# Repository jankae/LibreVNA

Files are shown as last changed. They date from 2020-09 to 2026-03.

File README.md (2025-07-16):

# LibreVNA

  

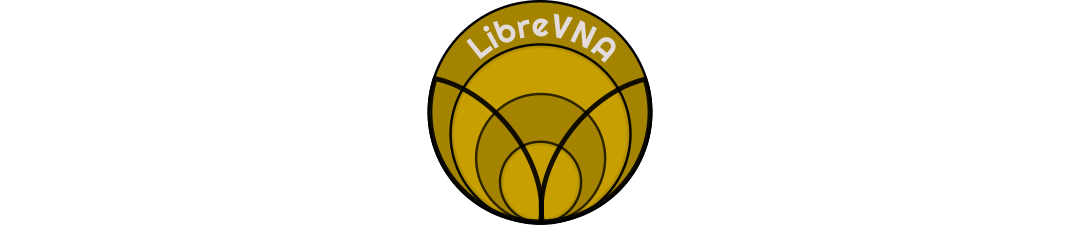
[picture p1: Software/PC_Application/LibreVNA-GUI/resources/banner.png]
LibreVNA


**100kHz to 6GHz VNA**

This is the improved version of my [first attempt](https://www.github.com/jankae/VNA) at a VNA.

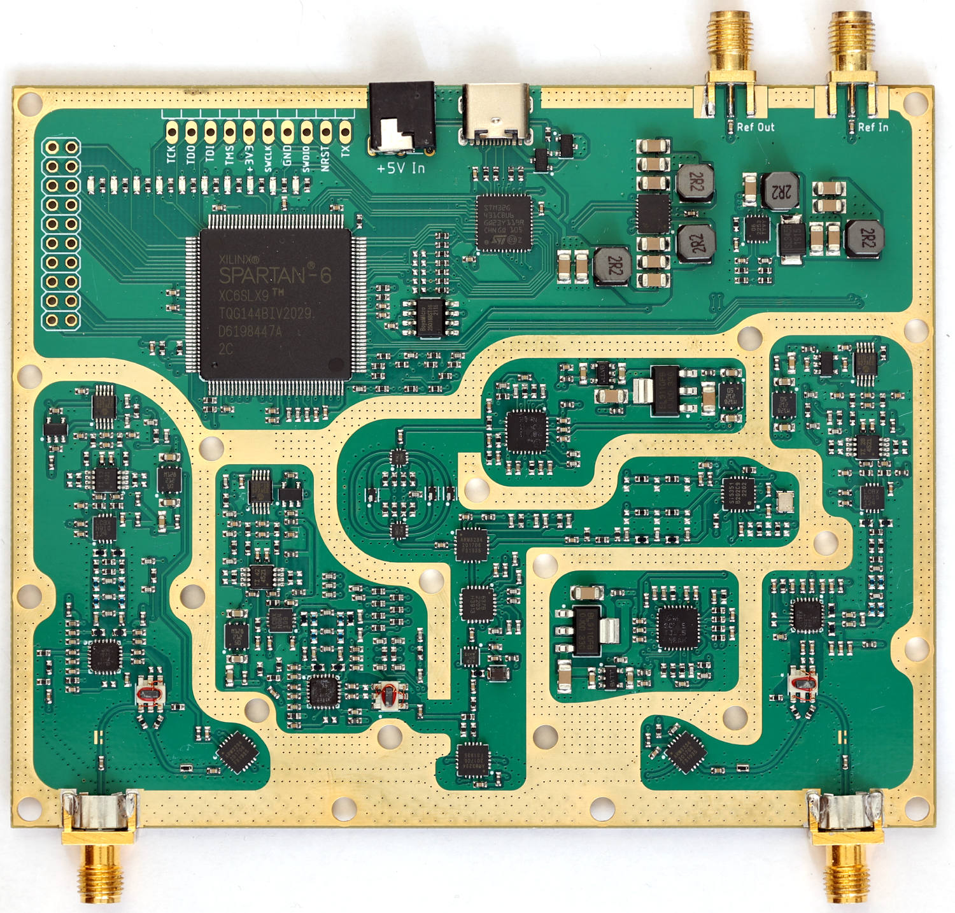
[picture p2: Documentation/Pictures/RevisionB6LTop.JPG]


## GUI Installation

### Windows
* Download the latest [Release](https://github.com/jankae/LibreVNA/releases) and unpack the zip file
* Start the included LibreVNA-GUI.exe
* No installation or driver is required, simply move the extracted folder somewhere convenient

### Ubuntu
* Download the latest [Release](https://github.com/jankae/LibreVNA/releases) and unpack the zip file
* Install the required libraries:
```console
sudo apt install qt6-base-dev libqt6svg6
```
* Install the udev rule (otherwise you don't have the permissions to access the USB device):
```console
wget https://raw.githubusercontent.com/jankae/LibreVNA/master/Software/PC_Application/51-vna.rules
sudo cp 51-vna.rules /etc/udev/rules.d
```
* Either reboot or reload the udev rules manually:
```console
sudo udevadm control --reload-rules
sudo udevadm trigger
```
* You can now start GUI:
```console
cd $UNPACKED_ZIP_FOLDER$
./LibreVNA-GUI
```

### MacOS
* Download the latest [Release](https://github.com/jankae/LibreVNA/releases)
  * If you are using MacOS 14+ use the release with `latest` in the name.
  * If you are using MacOS >13.7 use the release with  `13.7` in the name.
* Unpack the zip file and move LibreVNA-GUI.app to your `/Applications` folder.
* Start LibreVNA-GUI.app and add a security exception to allow the Mac to run the app with an "untrusted" signing key.
* Launch app again.

## Quick Start
* You can find released versions of the GUI application and the device firmware [here](https://github.com/jankae/LibreVNA/releases).
* If you would like to try out the newest features, the compiled versions of each commit can be found [here](https://github.com/jankae/LibreVNA/actions) (but keep in mind that some features might be unstable or incomplete). If you are having trouble downloading them, please refer to this [guide](Documentation/DeveloperInfo/DownloadActionBuilds.md).
* An (incomplete) [user manual](Documentation/UserManual/manual.pdf) is also available.
* If you would like to control the LibreVNA with a script, see the [SCPI Programming Guide](Documentation/UserManual/ProgrammingGuide.pdf).

Please also take a look at the [FAQ](Documentation/FAQ.md).

If you notice bugs or have ideas for improvements, please create an issue for that.

For general questions or discussions, the [LibreVNA group](https://groups.io/g/LibreVNA-support/) is probably the best place.

### Preliminary specifications
Some [specifications](Documentation/UserManual/specsheet.pdf) are available but this project is still under development and the specifications might change.

There are also some initial [example measurements](Documentation/Measurements/Measurements.md).

## How does it work?
The PCB is really only the RF frontend with some processing power. Everything else is handled in the PC application once the data is transferred via USB. You can try out the application without the PCB (obviously no measurements are possible, but you can import provided example measurements and get an idea about what it can and can't do).
### RF path:


* The main clock source is an Si5351C, providing all the required clocks for the different blocks. It also serves as the stimulus source for frequencies below 25MHz. Its own reference clock is either a 26MHz crystal or an external 10MHz signal.
* The stimulus source for frequencies above 25MHz is a MAX2871. Its output signal is slightly filtered to reduce the amount of harmonics.
* The stimulus signal power can be adjusted between approximately -42 and -10dbm with a digital attenuator (RFSA3714).
* After the amplifier(TRF37A73) the signal is split and the weaker part of it fed into the reference receiver.
* The stronger part of the signal can be routed to either port. In each signal path, two RF switches are used in series to achieve higher isolation between the ports.
* Instead of directional couplers, resistive return-loss-bridges are used (easier to implement for wide bandwidth).
* Both ports have completely separated receive paths. This increases BOM cost but allows measuring two parameters at once (S11 and S21 or S22 and S12). It also avoids potential isolation issues that could arise if the receive paths would merge into a single mixer/ADC.
* Each receiver consists of two down-convert mixers. The 1.IF sits at 60MHz, the 2.IF 250kHz.
* The ADCs are sampling the final IF with 16bit@800kHz.

### Digital section:


* The central element is the Spartan6 FPGA. It handles all communication with the RF blocks and samples the ADCs. This allows for nearly instant switching of the measurement frequency, only limited by the settling time of the PLLs.
* The microcontroller handles the setup of the sweep in the FPGA, extracts and preprocesses the measurements and passes them on through USB.
* The flash contains the FPGA bitstream. Because the microcontroller has access to the flash, no FPGA-related hardware tools (such as JTAG programmers) are needed, everything can be updated via USB.

### Power supply:


* Everything is powered from USB (or optionally by external 5V DC)
* Almost every RF block has its own local regulater, preventing noise and signals coupling into the supply lines from propagating across the whole PCB

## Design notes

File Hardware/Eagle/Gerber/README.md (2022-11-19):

### Stackup
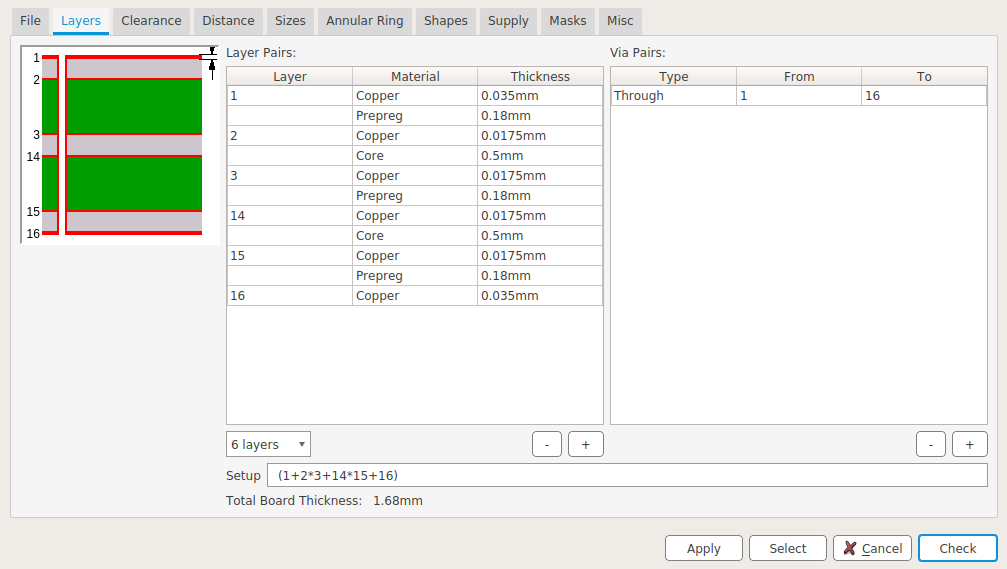
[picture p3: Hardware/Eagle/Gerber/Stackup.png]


* Exact thickness of the cores is not important, as long as they are significantly thicker than the prepregs
* Recommended Prepreg: 7628
* Example stackup from manufacturer: [JLC06161H-7628 Stackup](https://jlcpcb.com/impedance)

### PCB size

122mm * 98mm

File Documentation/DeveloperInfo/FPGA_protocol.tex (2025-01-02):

\documentclass{article}
\usepackage
[
        a4paper,% other options: a3paper, a5paper, etc
        left=2cm,
        right=2cm,
        top=2cm,
        bottom=2cm,
        % use vmargin=2cm to make vertical margins equal to 2cm.
        % us  hmargin=3cm to make horizontal margins equal to 3cm.
        % use margin=3cm to make all margins  equal to 3cm.
]
{geometry}
\usepackage{tikz}
\usepackage{siunitx} 
\usepackage{minibox}
\DeclareSIUnit{\belmilliwatt}{Bm}
\DeclareSIUnit{\dBm}{\deci\belmilliwatt}

\pgfdeclarelayer{background}
\pgfdeclarelayer{foreground}
\pgfsetlayers{background,main,foreground}

\newcommand{\bitrect}[2]{
  \begin{pgfonlayer}{foreground}
    \draw [thick] (0,0) rectangle (#1,1);
    \pgfmathsetmacro\result{#1-1}
    \foreach \x in {1,...,\result}
      \draw [thick] (\x,1) -- (\x, 0.8);
  \end{pgfonlayer}
%  \node [below left, align=right] at (0,0) {Type \\ Reset};
  \bitlabels{#1}{#2}
}
\newcommand{\rwbits}[3]{
  \draw [thick] (#1,0) rectangle ++(#2,1) node[pos=0.5]{#3};
  \pgfmathsetmacro\start{#1+0.5}
  \pgfmathsetmacro\finish{#1+#2-0.5}
%  \foreach \x in {\start,...,\finish}
%    \node [below, align=center] at (\x, 0) {R/W \\ 0};
}
\newcommand{\robits}[3]{
  \begin{pgfonlayer}{background}
    \draw [thick, fill=lightgray] (#1,0) rectangle ++(#2,1) node[pos=0.5]{#3};
  \end{pgfonlayer}
  \pgfmathsetmacro\start{#1+0.5}
  \pgfmathsetmacro\finish{#1+#2-0.5}
%  \foreach \x in {\start,...,\finish}
%    \node [below, align=center] at (\x, 0) {RO \\ 0};
}
\newcommand{\bitlabels}[2]{
  \foreach \bit in {1,...,#1}{
     \pgfmathsetmacro\result{#2}
     \node [above] at (\bit-0.5, 1) {\pgfmathprintnumber{\result}};
   }
}

\begin{document}

\section{Digital Interface}
\begin{center}
\begin{tabular}{ c|c|c }
Pin & Direction & Function\\
 \hline
SCK & in & SCK for SPI communication/SCK for PLL communication\\
MOSI & in & MOSI for SPI communication/MOSI for PLL communication\\
MISO & out & MISO for SPI communication/MUX for PLL communication\\
NSS & in & Chip Select for SPI communication/LE for PLL communication\\
INTR & out & Active high interrupt indicator\\
RESET\footnotemark & in & FPGA reset\\
AUX1 & in & Selector for direct communication with Source PLL\\
AUX2 & in & Selector for direct communication with LO PLL\\
AUX3 & in & Active low sweep enable. Has to be high when changing settings\\
Trigger In\footnotemark & in & Trigger input for synchronization across devices\\
Trigger Out\footnotemark & Out & Trigger output for synchronization across devices\\
\end{tabular}
\end{center}
\footnotetext[1]{Reset is named "MCU\_FPGA\_UNUSED1" in the schematic as this is a later software addition}
\footnotetext[2]{Trigger In is named "MCU\_FPGA\_UNUSED2" in the schematic as this is a later software addition}
\footnotetext[3]{Trigger Out is named "MCU\_FPGA\_UNUSED3" in the schematic as this is a later software addition}
Depending on the voltage on AUX1/AUX2 the SPI port controls either the FPGA or one of the MAX2871 PLLs:
\begin{center}
\begin{tabular}{ c|c|c }
AUX1 & AUX2 & Function\\
 \hline
low & low & SPI communication with FPGA\\
high & low & Direct feedthrough of SCK, MOSI, MISO and NSS to Source PLL\\
low & high & Direct feedthrough of SCK, MOSI, MISO and NSS to LO PLL\\
high & high & Invalid\\
\end{tabular}
\end{center}
When communicating with a PLL, the MUX output of the MAX2871 is forwarded to MISO and the NSS signal is forwarded to the LE pin. As the LE pin should stay low until after a valid register has been shifted in (see MAX2871 datasheet), set NSS low before switching to PLL communication mode.

\section{SPI Protocol}
Each SPI transfer starts with pulling NSS low and ends with NSS returning to high level. SPI communication is done in words of 16\,bits. The first word after NSS is pulled low is the command word and determines the amount and meaning of the following words.
The word received while transmitting the command word is the interrupt status register:
\begin{center}
\begin{tikzpicture}
\bitrect{16}{16-\bit}
\robits{0}{10}{reserved}
\rwbits{10}{1}{DFT}
\rwbits{11}{1}{SH}
\rwbits{12}{1}{OR}
\rwbits{13}{1}{ND}
\rwbits{14}{1}{SU}
\rwbits{15}{1}{LU}
\end{tikzpicture}
\end{center}
\begin{itemize}
\item \textbf{DFT:} New DFT result available (see section~\ref{dft}).
\item \textbf{SH:} Sweep halted due to halt bit set. Sweep will be resumed once the resume command is issued.
\item \textbf{OR:} Data overrun occured (only cleared by resetting the FPGA)
\item \textbf{ND:} New data available
\item \textbf{SU:} Source unlocked
\item \textbf{LU:} LO unlocked
\end{itemize}
\subsection{Writing a register}
Writing a register requires the transfer of two words: First the control word selecting the destination address and a second word containing the new register value:
\begin{center}
\begin{tikzpicture}
\bitrect{16}{16-\bit}
\rwbits{0}{1}{1}
\rwbits{1}{1}{0}
\rwbits{2}{1}{0}
\robits{3}{8}{reserved}
\rwbits{11}{5}{Register Address}
\end{tikzpicture}
\begin{tikzpicture}
\bitrect{16}{16-\bit}
\rwbits{0}{16}{Register Value}
\end{tikzpicture}
\end{center}
\subsection{Writing SweepConfig}
Initiate the sweep config transfer by sending the command word:
\begin{center}
\begin{tikzpicture}
\bitrect{16}{16-\bit}
\rwbits{0}{1}{0}
\rwbits{1}{1}{0}
\rwbits{2}{1}{0}
\rwbits{3}{13}{Sweep point}
\end{tikzpicture}
\end{center}
The maximum number of points per sweep is 4501, thus the highest valid value for "Sweep point" is 4500. After the control word, send the six words of the sweep config (see section~\ref{sweepconfig}) while keeping NSS low. The sweep config is transmitted MSB first.

\subsection{Reading a sampling result}
Whenever the ND bit in the interrupt status register is set, new sampling data is available and can be read via SPI. It has to be read before the next sampling data arrives otherwise the old data will be overwritten.

Initiate the reading of sampling data by sending the command word:
\begin{center}
\begin{tikzpicture}
\bitrect{16}{16-\bit}
\rwbits{0}{1}{1}
\rwbits{1}{1}{1}
\rwbits{2}{1}{0}
\robits{3}{13}{reserved}
\end{tikzpicture}
\end{center}
Afterwards, read up to 19 words before setting NSS high. These 19 words will contain the sampling result (see section~\ref{result}), transmitted with the least significant word first.

\subsection{Resuming a halted sweep}
When the halt bit is set in the SweepConfig, the FPGA will configure the Source and LO as requested but will not start the settling timer (and subsequently the sampling process) until this resume command is issued. The halted sweep is indicated by the sweep halted bit in the status register.
\begin{center}
\begin{tikzpicture}
\bitrect{16}{16-\bit}
\rwbits{0}{1}{0}
\rwbits{1}{1}{0}
\rwbits{2}{1}{1}
\robits{3}{13}{reserved}
\end{tikzpicture}
\end{center}

\subsection{Reading ADC limits}
The FPGA keeps track of the highest and lowest sample of each ADC to detect saturation and verify signal levels.

Initiate the reading of ADC limit data by sending the command word:
\begin{center}
\begin{tikzpicture}
\bitrect{16}{16-\bit}
\rwbits{0}{1}{1}
\rwbits{1}{1}{1}
\rwbits{2}{1}{1}
\robits{3}{13}{reserved}
\end{tikzpicture}
\end{center}
Afterwards, read 6 words before setting NSS high. These 6 words will contain the sampling result:

\begin{center}
\begin{tikzpicture}
\bitrect{16}{96-\bit}
\rwbits{0}{16}{Port 1 minimum}
\end{tikzpicture}
\begin{tikzpicture}
\bitrect{16}{80-\bit}
\rwbits{0}{16}{Port 1 maximum}
\end{tikzpicture}
\begin{tikzpicture}
\bitrect{16}{64-\bit}
\rwbits{0}{16}{Port 2 minimum}
\end{tikzpicture}
\begin{tikzpicture}
\bitrect{16}{48-\bit}
\rwbits{0}{16}{Port 2 maximum}
\end{tikzpicture}
\begin{tikzpicture}
\bitrect{16}{32-\bit}
\rwbits{0}{16}{Reference minimum}
\end{tikzpicture}
\begin{tikzpicture}
\bitrect{16}{16-\bit}
\rwbits{0}{16}{Reference maximum}
\end{tikzpicture}
\end{center}

\subsection{Resetting the ADC limit}
Issuing this command result in all minimum values set to 32767 and all maximum values set to -32768.
\begin{center}
\begin{tikzpicture}
\bitrect{16}{16-\bit}
\rwbits{0}{1}{0}
\rwbits{1}{1}{1}
\rwbits{2}{1}{1}
\robits{3}{13}{reserved}
\end{tikzpicture}
\end{center}

\subsection{Reading the DFT result}
Initiate the reading of the DFT result (see section~\ref{dft}) by sending the command word:
\begin{center}
\begin{tikzpicture}
\bitrect{16}{16-\bit}
\rwbits{0}{1}{1}
\rwbits{1}{1}{0}
\rwbits{2}{1}{1}
\robits{3}{13}{reserved}
\end{tikzpicture}
\end{center}
Afterwards, read 12 words before setting NSS high. These 12 words will contain the first bin of the DFT, the least significant word is transmitted first:
\begin{center}
\begin{tikzpicture}
\bitrect{16}{192-\bit}
\rwbits{0}{16}{Port 1 I[47:32]}
\end{tikzpicture}
\begin{tikzpicture}
\bitrect{16}{176-\bit}
\rwbits{0}{16}{Port 1 I[31:16]}
\end{tikzpicture}
\begin{tikzpicture}
\bitrect{16}{168-\bit}
\rwbits{0}{16}{Port 1 I[15:0]}
\end{tikzpicture}
\begin{tikzpicture}
\bitrect{16}{144-\bit}
\rwbits{0}{16}{Port 1 Q[47:32]}
\end{tikzpicture}
\begin{tikzpicture}
\bitrect{16}{128-\bit}
\rwbits{0}{16}{Port 1 Q[31:16]}
\end{tikzpicture}
\begin{tikzpicture}
\bitrect{16}{112-\bit}
\rwbits{0}{16}{Port 1 Q[15:0]}
\end{tikzpicture}
\begin{tikzpicture}
\bitrect{16}{96-\bit}
\rwbits{0}{16}{Port 2 I[47:32]}
\end{tikzpicture}
\begin{tikzpicture}
\bitrect{16}{80-\bit}
\rwbits{0}{16}{Port 2 I[31:16]}
\end{tikzpicture}
\begin{tikzpicture}
\bitrect{16}{64-\bit}
\rwbits{0}{16}{Port 2 I[15:0]}
\end{tikzpicture}
\begin{tikzpicture}
\bitrect{16}{48-\bit}
\rwbits{0}{16}{Port 2 Q[47:32]}
\end{tikzpicture}
\begin{tikzpicture}
\bitrect{16}{32-\bit}
\rwbits{0}{16}{Port 2 Q[31:16]}
\end{tikzpicture}
\begin{tikzpicture}
\bitrect{16}{16-\bit}
\rwbits{0}{16}{Port 2 Q[15:0]}
\end{tikzpicture}
\end{center}
Repeating this procedure will return the next DFT bin. For each bin, the CS pin has to be toggled and the command word needs to be sent again (each DFT bin requires a new SPI transaction). The DFT interrupt is reset once all bins have been read. Alternatively, toggling the DFT off and on (by disabling and enabling its interrupt) will also reset the interrupt flag.

\section{Registers}
\subsection{Interrupt Mask Register: 0x00}
\begin{center}
\begin{tikzpicture}
\bitrect{16}{16-\bit}
\robits{0}{10}{reserved}
\rwbits{10}{1}{DFTIE}
\rwbits{11}{1}{SHIE}
\rwbits{12}{1}{ORIE}
\rwbits{13}{1}{NDIE}
\rwbits{14}{1}{SUIE}
\rwbits{15}{1}{LUIE}
\end{tikzpicture}
\end{center}
\begin{itemize}
\item \textbf{DFTIE:} DFT interrupt enable. This bit also enables the DFT (see section~\ref{dft}).
\item \textbf{SHIE:} Sweep halted interrupt enable
\item \textbf{ORIE:} Data overrun interrupt enable 
\item \textbf{NDIE:} New data interrupt enable
\item \textbf{SUIE:} Source unlocked interrupt enable
\item \textbf{LUIE:} LO unlocked interrupt enable 
\end{itemize}

\subsection{Sweep Points Register: 0x01}
\begin{center}
\begin{tikzpicture}
\bitrect{16}{16-\bit}
\rwbits{0}{16}{Number of points per sweep - 1}
\end{tikzpicture}
\end{center}
The register contains the number of points per sweep negative one, e.g. set to 11b if the sweep contains four points.

\subsection{Samples Per Point Register: 0x02}
\label{reg:spp}
\begin{center}
\begin{tikzpicture}
\bitrect{16}{16-\bit}
\robits{0}{3}{reserved}
\rwbits{3}{13}{SPP[12:0]}
\end{tikzpicture}
\end{center}
\begin{itemize}
\item \textbf{SPP[12:0]:} The register contains the number of samples per point in increments of 16 samples (e.g. SPP=0b0000001000=0x08 uses 128 samples per point). The value of this register is only used if SweepConfig[92:90] is set to 000. Otherwise it is overwritten for the sweep point with one of seven preselected values.
\end{itemize}

\subsection{System Control Register: 0x03}
\begin{center}
\begin{tikzpicture}
\footnotesize
\bitrect{16}{16-\bit}
\rwbits{0}{1}{P1EN}
\rwbits{1}{1}{P2EN}
\rwbits{2}{1}{REN}
\rwbits{3}{1}{AMEN}
\rwbits{4}{1}{SOEN}
\rwbits{5}{1}{LOEN}
\rwbits{6}{1}{RLED}
\rwbits{7}{1}{LED6}
\rwbits{8}{1}{LED7}
\rwbits{9}{2}{Window[1:0]}
\rwbits{11}{1}{SCEN}
\rwbits{12}{1}{LCEN}
\robits{13}{1}{reserved}
%\rwbits{13}{1}{EXP2}
\rwbits{14}{1}{SYM}
\rwbits{15}{1}{PSEN}
\end{tikzpicture}
\end{center}
\begin{itemize}
\item \textbf{P1EN:} Port 1 Mixers/Amplifier enable
\item \textbf{P2EN:} Port 2 Mixers/Amplifier enable
\item \textbf{REN:} Reference Mixers/Amplifier enable
\item \textbf{AMEN:} Source amplifier enable
\item \textbf{SOEN:} Source enable
\item \textbf{LOEN:} LO enable
\item \textbf{RLED:} External frequency LED control
\item \textbf{LED6:}{User LED 6 control}
\item \textbf{LED7:}{User LED 7 control}
\item \textbf{Window[1:0]:}{Type of window to be used in calculation of real/imag of the sampling result}
\begin{center}
\begin{tabular}{ c|c }
Setting & Window type\\
 \hline
00 & Rectangular (no window)\\
01 & Kaiser\\
10 & Hann\\
11 & Flat Top\\
\end{tabular}
\end{center}
\item \textbf{SCEN:}{Source chip enable}
\item \textbf{LCEN:}{LO chip enable}
%\item \textbf{EXP1:}{Excite Port1 during sweep}
\item \textbf{SYM:}{Sync master, see also section~\ref{synchronization}. If multiple devices are combined, exactly one must have this bit set.}
\item \textbf{PSEN:}{Port switch enable}
\end{itemize}

\subsection{ADC Prescaler register: 0x04}
\label{reg:ADC}
\begin{center}
\begin{tikzpicture}
\bitrect{16}{16-\bit}
\robits{0}{8}{reserved}
\rwbits{8}{8}{Presc[7:0]}
\end{tikzpicture}
\end{center}
\begin{itemize}
\item \textbf{Presc[7:0]:} Amount of FPGA clock cycles between ADC samples.
$$ SR_{ADC} = \frac{\SI{102.4}{\mega\hertz}}{Presc} $$
The minimum value for this register is 112, which results in a samplerate of roughly \SI{914.3}{\kilo\hertz}. If Presc is set to a lower value, the data acquisition from the ADC is not done when the next sample starts and samples will be skipped.
\end{itemize}

\subsection{Phase Increment: 0x05}
\label{reg:phaseinc}
\begin{center}
\begin{tikzpicture}
\bitrect{16}{16-\bit}
\robits{0}{4}{reserved}
\rwbits{4}{12}{Phase Increment[11:0]}
\end{tikzpicture}
\end{center}
\begin{itemize}
\item \textbf{Phase Increment[7:0]:} Phase angle between ADC samples for DFT bin calculation in $\frac{2\pi}{4096}$rad.
For a given ADC samplerate $SR_{ADC}$ and final IF frequency $f_{IF2}$ set this value to
$$ PhaseInc = \frac{4096 * f_{IF2}}{SR_{ADC}} $$
For the the default IF frequency of $f_{IF2} = \SI{250}{\kilo\hertz}$ this evaluates to 10*Presc (see ADC prescaler register).
\end{itemize}

\subsection{Sweep setup: 0x06}
Each point in the sweep is done in stages. Each stage consists of (optionally) routing the source signal to one of the ports and sampling of all ADCs. A "new data" interrupt is triggered after each stage.
\label{reg:sweepsetup}
\begin{center}
\begin{tikzpicture}
\bitrect{16}{16-\bit}
\rwbits{0}{3}{Stages}
\rwbits{3}{1}{SYNC}
\robits{4}{6}{reserved}
\rwbits{10}{3}{Port 1 stage}
\rwbits{13}{3}{Port 2 stage}
\end{tikzpicture}
\end{center}
\begin{itemize}
\item \textbf{Stages} Number of stages per point - 1. Normally the number of stages is equal to the number of ports but it can also be less (e.g. if only S11 is measured).
\item \textbf{SYNC:} Enables synchronization mode (see section~\ref{synchronization}).
\item \textbf{Port 1 stage} Number of stage during which the source signal is routed to port 1. Must not have the same value as Port 2 stage.
\item \textbf{Port 2 stage} Number of stage during which the source signal is routed to port 2. Must not have the same value as Port 1 stage.
\end{itemize}

\subsection{Hardware override register: 0x07}
Allows overwriting hardware settings, regardless of whether a sweep is active or not.
\label{reg:hw_override}
\begin{center}
\begin{tikzpicture}
\bitrect{16}{16-\bit}
\rwbits{0}{1}{OWE}
\rwbits{1}{7}{Attenuator[6:0]}
\rwbits{8}{2}{SourceFilter}
\rwbits{10}{1}{BS}
\rwbits{11}{1}{P1EN}
\rwbits{12}{1}{P2EN}
\robits{13}{3}{reserved}
\end{tikzpicture}
\end{center}
\begin{itemize}
\item \textbf{OWE:} Overwrite enable. If 1, this register is used to configure the hardware. If 0, all other bits in the register are ignored. Must be set to 0 for valid sweep operation.
\item \textbf{Attenuator[6:0]:} Attenuator setting
\item \textbf{SourceFilter:} Low pass filter selection for source signal
\begin{center}
\begin{tabular}{ c|c }
Setting & Selected Band\\
 \hline
00 & \SIrange{0}{900}{\mega\hertz}\\
01 & \SIrange{900}{1800}{\mega\hertz}\\
10 & \SIrange{1800}{3500}{\mega\hertz}\\
11 & \SIrange{3500}{6000}{\mega\hertz}\\
\end{tabular}
\end{center}
\item \textbf{BS: Band select.} Set to 0 for highband, set to 1 for lowband.
\item \textbf{P1EN:} Route signal to port 1. Must not be enabled at the same time as P2EN.
\item \textbf{P2EN:} Route signal to port 2. Must not be enabled at the same time as P1EN.
\end{itemize}

\subsection{MAX2871 Default Values Registers: 0x08-0x0F}
See datasheet of MAX2871 for bit descriptions. Bits for the fields N, FRAC, M, VCO and DIV\_A are "don't care" as they will be overwritten by the SweepConfig setting.
\begin{center}
\begin{tikzpicture}
\bitrect{16}{16-\bit}
\rwbits{0}{16}{MAX2871 Register 0[15:0]}
\end{tikzpicture}
\begin{tikzpicture}
\bitrect{16}{16-\bit}
\rwbits{0}{16}{MAX2871 Register 0[31:16]}
\end{tikzpicture}
\begin{tikzpicture}
\bitrect{16}{16-\bit}
\rwbits{0}{16}{MAX2871 Register 1[15:0]}
\end{tikzpicture}
\begin{tikzpicture}
\bitrect{16}{16-\bit}
\rwbits{0}{16}{MAX2871 Register 1[31:16]}
\end{tikzpicture}
\begin{tikzpicture}
\bitrect{16}{16-\bit}
\rwbits{0}{16}{MAX2871 Register 3[15:0]}
\end{tikzpicture}
\begin{tikzpicture}
\bitrect{16}{16-\bit}
\rwbits{0}{16}{MAX2871 Register 3[31:16]}
\end{tikzpicture}
\begin{tikzpicture}
\bitrect{16}{16-\bit}
\rwbits{0}{16}{MAX2871 Register 4[15:0]}
\end{tikzpicture}
\begin{tikzpicture}
\bitrect{16}{16-\bit}
\rwbits{0}{16}{MAX2871 Register 4[31:16]}
\end{tikzpicture}
\end{center}

\subsection{DFT registers}
\label{dft}
In addition to the single bin DFT configured through the ADC prescaler and phase increment registers (see \ref{reg:ADC} and \ref{reg:phaseinc}), the FPGA also includes a multiple point DFT. This DFT only operates on the port 1 and port 2 receivers and is intended to speed up spectrum analyzer measurements. If enabled, the DFT runs in parallel to all other calculations.

The DFT has a fixed number of bins (96), but the frequencies these bins correspond to can be changed.

\subsubsection{DFT\_FIRST\_BIN: 0x12}
\begin{center}
\begin{tikzpicture}
\bitrect{16}{16-\bit}
\rwbits{0}{16}{DFT\_FIRST\_BIN[15:0]}
\end{tikzpicture}
\end{center}
\begin{itemize}
\item \textbf{DFT\_FIRST\_BIN[15:0]:} This value determines the frequency corresponding to the first DFT bin.
$$ f_{firstBin} =  \frac{SR_{ADC} * DFT\_FIRST\_BIN}{2^{16}}$$
\end{itemize}

\subsubsection{DFT\_FREQ\_SPACING: 0x13}
\begin{center}
\begin{tikzpicture}
\bitrect{16}{16-\bit}
\rwbits{0}{16}{DFT\_FREQ\_SPACING[15:0]}
\end{tikzpicture}
\end{center}
\begin{itemize}
\item \textbf{DFT\_FREQ\_SPACING[15:0]:} This value determines the frequency difference between bins.
$$ \Delta f =  \frac{SR_{ADC} * DFT\_FREQ\_SPACING}{2^{24}}$$
\end{itemize}

\subsection{SETTLING\_TIME: 0x14}
\begin{center}
\begin{tikzpicture}
\bitrect{16}{16-\bit}
\rwbits{0}{16}{SETTLING\_TIME[15:0]}
\end{tikzpicture}
\end{center}
\begin{itemize}
\item \textbf{SETTLING\_TIME[19:0]:} This value determines the time delay between applying the stimulus signal and the beginning of the ADC sampling.
$$ t_{delay} =  \frac{1}{\SI{102.4}{\mega\hertz}} SETTLING\_TIME $$
\end{itemize}
\subsection{SETTLING\_TIME: 0x15}
\begin{center}
\begin{tikzpicture}
\bitrect{16}{16-\bit}
\robits{0}{12}{reserved}
\rwbits{12}{4}{SETTLING\_TIME[19:16]}
\end{tikzpicture}
\end{center}

\section{SweepConfig}
\label{sweepconfig}
The SweepConfig contains data for the source and LO1 PLL as well as the attenuator and source filter. Each point in the sweep, needs a valid SweepConfig before the sweep is started.

\begin{center}
\begin{tikzpicture}
\bitrect{16}{96-\bit}
\rwbits{0}{1}{HS}
%\rwbits{1}{2}{SettlingTime}
\rwbits{1}{1}{\tiny LO N[6]}
\rwbits{2}{1}{\minibox{\tiny Source\\N[6]}}
\rwbits{3}{3}{Samples}
\rwbits{6}{2}{SourceFilter}
\rwbits{8}{8}{LO M[11:4]}
\end{tikzpicture}
\begin{tikzpicture}
\bitrect{16}{80-\bit}
\rwbits{0}{4}{LO M[3:0]}
\rwbits{4}{12}{LO FRAC[11:0]}
\end{tikzpicture}
\begin{tikzpicture}
\bitrect{16}{64-\bit}
\rwbits{0}{3}{LO DIV\_A[2:0]}
\rwbits{3}{6}{LO VCO[5:0]}
\rwbits{9}{6}{LO N[5:0]}
\rwbits{15}{1}{BS}
\end{tikzpicture}
\begin{tikzpicture}
\bitrect{16}{48-\bit}
\rwbits{0}{2}{PWR[1:0]}
\rwbits{2}{7}{Attenuator[6:0]}
\rwbits{9}{7}{Source M[11:5]}
\end{tikzpicture}
\begin{tikzpicture}
\bitrect{16}{32-\bit}
\rwbits{0}{5}{Source M[4:0]}
\rwbits{5}{11}{Source FRAC[11:1]}
\end{tikzpicture}
\begin{tikzpicture}
\bitrect{16}{16-\bit}
\rwbits{0}{1}{F[0]}
\rwbits{1}{3}{Source DIV\_A[2:0]}
\rwbits{4}{6}{Source VCO[5:0]}
\rwbits{10}{6}{Source N[5:0]}
\end{tikzpicture}
\end{center}
\begin{itemize}
\item \textbf{HS: Halt sweep.} If set, settling and sampling of this sweep point will be postponed until the sweep resume command is issued.
%\item \textbf{SettlingTime:} Amount of time between locking of PLLs and beginning of ADC sampling
%\begin{center}
%\begin{tabular}{ c|c }
%Setting & Time\\
 %\hline
%00 & \SI{20}{\micro\second}\\
%01 & \SI{60}{\micro\second}\\
%10 & \SI{180}{\micro\second}\\
%11 & \SI{540}{\micro\second}\\
%\end{tabular}
%\end{center}
\item \textbf{Samples:} Number of ADC samples to take
\begin{center}
\begin{tabular}{ c|c|c }
Setting & Samples & Equivalent IF bandwidth\\
 \hline
000 & Defined by SPP register & \SI{914}{\kilo\hertz}/SPP\\
001 & 96 & \SI{10}{\kilo\hertz}\\
010 & 304 & \SI{3}{\kilo\hertz}\\
011 & 912 & \SI{1}{\kilo\hertz}\\
100 & 3040 & \SI{300}{\hertz}\\
101 & 9136 & \SI{100}{\hertz}\\
110 & 30464 & \SI{30}{\hertz}\\
111 & 91392 & \SI{10}{\hertz}\\
\end{tabular}
\end{center}
\item \textbf{SourceFilter:} Low pass filter selection for source signal
\begin{center}
\begin{tabular}{ c|c }
Setting & Selected Band\\
 \hline
00 & \SIrange{0}{900}{\mega\hertz}\\
01 & \SIrange{900}{1800}{\mega\hertz}\\
10 & \SIrange{1800}{3500}{\mega\hertz}\\
11 & \SIrange{3500}{6000}{\mega\hertz}\\
\end{tabular}
\end{center}
\item \textbf{BS: Band select.} Set to 0 for highband, set to 1 for lowband.
\item \textbf{PWR:} Power setting of source PLL. Will be written to register 4, bits [4:3] of the source PLL, controlling the output power of output A.
\begin{center}
\begin{tabular}{ c|c }
Setting & Selected Power\\
 \hline
00 & \SI{-4}{\dBm}\\
01 & \SI{-1}{\dBm}\\
10 & \SI{2}{\dBm}\\
11 & \SI{5}{\dBm}\\
\end{tabular}
\end{center}
\item \textbf{Attenuator:} Attenuation of source signal in \SI{0.25}{\decibel}.
\end{itemize}

\section{Sampling Result}
\label{result}
Each point in the sweep generates a sampling results for each stage (see section~\ref{reg:sweepsetup}).
\begin{center}
\begin{tikzpicture}
\bitrect{16}{304-\bit}
\rwbits{0}{3}{STAGE[2:0]}
\rwbits{3}{13}{POINT\_NUMBER[12:0]}
\end{tikzpicture}
\begin{tikzpicture}
\bitrect{16}{288-\bit}
\rwbits{0}{16}{Port 1 I[47:32]}
\end{tikzpicture}
\begin{tikzpicture}
\bitrect{16}{272-\bit}
\rwbits{0}{16}{Port 1 I[31:16]}
\end{tikzpicture}
\begin{tikzpicture}
\bitrect{16}{256-\bit}
\rwbits{0}{16}{Port 1 I[15:0]}
\end{tikzpicture}

\begin{tikzpicture}
\bitrect{16}{240-\bit}
\rwbits{0}{16}{Port 1 Q[47:32]}
\end{tikzpicture}
\begin{tikzpicture}
\bitrect{16}{224-\bit}
\rwbits{0}{16}{Port 1 Q[31:16]}
\end{tikzpicture}
\begin{tikzpicture}
\bitrect{16}{208-\bit}
\rwbits{0}{16}{Port 1 Q[15:0]}
\end{tikzpicture}

\begin{tikzpicture}
\bitrect{16}{192-\bit}
\rwbits{0}{16}{Port 2 I[47:32]}
\end{tikzpicture}
\begin{tikzpicture}
\bitrect{16}{176-\bit}
\rwbits{0}{16}{Port 2 I[31:16]}
\end{tikzpicture}
\begin{tikzpicture}
\bitrect{16}{160-\bit}
\rwbits{0}{16}{Port 2 I[15:0]}
\end{tikzpicture}

\begin{tikzpicture}
\bitrect{16}{144-\bit}
\rwbits{0}{16}{Port 2 Q[47:32]}
\end{tikzpicture}
\begin{tikzpicture}
\bitrect{16}{128-\bit}
\rwbits{0}{16}{Port 2 Q[31:16]}
\end{tikzpicture}
\begin{tikzpicture}
\bitrect{16}{112-\bit}
\rwbits{0}{16}{Port 2 Q[15:0]}
\end{tikzpicture}

\begin{tikzpicture}
\bitrect{16}{96-\bit}
\rwbits{0}{16}{Reference Signal I[47:32]}
\end{tikzpicture}
\begin{tikzpicture}
\bitrect{16}{80-\bit}
\rwbits{0}{16}{Reference Signal I[31:16]}
\end{tikzpicture}
\begin{tikzpicture}
\bitrect{16}{64-\bit}
\rwbits{0}{16}{Reference Signal I[15:0]}
\end{tikzpicture}

\begin{tikzpicture}
\bitrect{16}{48-\bit}
\rwbits{0}{16}{Reference Signal Q[47:32]}
\end{tikzpicture}
\begin{tikzpicture}
\bitrect{16}{32-\bit}
\rwbits{0}{16}{Reference Signal Q[31:16]}
\end{tikzpicture}
\begin{tikzpicture}
\bitrect{16}{16-\bit}
\rwbits{0}{16}{Reference Signal Q[15:0]}
\end{tikzpicture}
\end{center}

\section{Synchronization}
\label{synchronization}
The FPGA supports synchronization of the sweep across multiple devices. This feature can be enabled by setting the SYNC bit in the sweep setup register (see section~\ref{reg:sweepsetup}). When enabled, the following conditions must be met:
\begin{itemize}
\item All participating devices must be connected in a loop via the trigger input and output pins. The order of the devices is not important.
\item All devices must use the same sweep settings with the exception of the "Port 1 stage" and "Port 2 stage" settings in the sweep setup register.
\item The port stages must be configured in such a way, that for each stage exactly one port is active in one device.
\end{itemize}

The synchronization works by delaying sampling until the stimulus signal is present, even when generated by another device. For each sampling stage, performs the following steps:
\begin{itemize}
\item When the device is the synchronization master (SYM bit set):
\begin{itemize}
\item Set up source and 1.LO PLLs
\item If applicable: wait for the "resume sweep" command
\item Set the trigger output to high
\item Wait for high level on trigger input
\item Sample ADCs
\item Set the trigger output to low
\item Wait for low level on trigger input
\end{itemize}
\item When the device is the synchronization slave (SYM bit not set):
\begin{itemize}
\item Set 1.LO PLL
\item If applicable: wait for the "resume sweep" command
\item Wait for high level on trigger input
\item Set trigger output to high
\item Sample ADCs
\item Wait for low level on trigger input
\item Set the trigger output to low
\end{itemize}
\end{itemize}

\end{document}

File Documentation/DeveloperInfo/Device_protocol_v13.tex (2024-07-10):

\documentclass[a4paper,11pt]{article}
\usepackage{titlesec}
\titleformat{\paragraph}
{\normalfont\normalsize\bfseries}{\theparagraph}{1em}{}
\titlespacing*{\paragraph}
{0pt}{3.25ex plus 1ex minus .2ex}{1.5ex plus .2ex}

\usepackage[utf8]{inputenc}
\usepackage[T1]{fontenc} % LY1 also works
\usepackage[margin=1in]{geometry}
\usepackage{tabularx}
%% Font settings suggested by fbb documentation.
\usepackage{textcomp} % to get the right copyright, etc.
\usepackage[lining,tabular]{fbb} % so math uses tabular lining figures
\usepackage[scaled=.95,type1]{cabin} % sans serif in style of Gill Sans
\usepackage[varqu,varl]{zi4}% inconsolata typewriter
\useosf % change normal text to use proportional oldstyle figures
%\usetosf would provide tabular oldstyle figures in text

\usepackage{microtype}
\usepackage{siunitx}
\DeclareSIUnit{\belmilliwatt}{Bm}
\DeclareSIUnit{\dBm}{\deci\belmilliwatt}
\sisetup{range-phrase=--, range-units=single, binary-units = true}
\usepackage{graphicx}
\usepackage{tikz}
\usepackage{svg}
%\usepackage{hyperref}
\usetikzlibrary{arrows, shadows}
\tikzset{%
  cascaded/.style = {%
    general shadow = {%
      shadow scale = 1,
      shadow xshift = -1ex,
      shadow yshift = 1ex,
      draw,
      thick,
      fill = white},
    general shadow = {%
      shadow scale = 1,
      shadow xshift = -.5ex,
      shadow yshift = .5ex,
      draw,
      thick,
      fill = white},
    fill = white, 
    draw,
    thick,
    minimum width = 1.5cm,
    minimum height = 2cm}}
    
\usepackage{enumitem}
\setitemize{noitemsep,topsep=0pt,parsep=0pt,partopsep=0pt}
\setenumerate{noitemsep,topsep=0pt,parsep=0pt,partopsep=0pt}
\setlist{leftmargin=*}
\usepackage{listings}
\lstset{
	basicstyle=\ttfamily,
	frame=single,
	breaklines=true,
	morecomment=[l][\color{green}]{\#},
}
\usepackage[os=win]{menukeys}
\renewmenumacro{\keys}[+]{shadowedroundedkeys}

\usepackage{booktabs,caption}
\usepackage{threeparttable}
\newcolumntype{L}[1]{>{\raggedright\let\newline\\\arraybackslash\hspace{0pt}}m{#1}}
\newcolumntype{C}[1]{>{\centering\let\newline\\\arraybackslash\hspace{0pt}}m{#1}}
\newcolumntype{R}[1]{>{\raggedleft\let\newline\\\arraybackslash\hspace{0pt}}m{#1}}
\usepackage{tabularx} 

\usepackage{multirow}
\usepackage{longtable,booktabs,threeparttablex}

\usepackage{stackengine}
\usepackage{scalerel}
\usepackage{xcolor,mdframed}

\newcommand\danger[1][5ex]{%
  \renewcommand\stacktype{L}%
  \scaleto{\stackon[1.3pt]{\color{red}$\triangle$}{\tiny !}}{#1}%
}

\newenvironment{important}[1][]{%
   \begin{mdframed}[%
      backgroundcolor={red!15}, hidealllines=true,
      skipabove=0.7\baselineskip, skipbelow=0.7\baselineskip,
      splitbottomskip=2pt, splittopskip=4pt, #1]%
   \makebox[0pt]{% ignore the withd of !
      \smash{% ignor the height of !
         %\fontsize{32pt}{32pt}\selectfont% make the ! bigger
         \hspace*{-45pt}% move ! to the left
         \raisebox{-5pt}{% move ! up a little
            {\danger}% type the bold red !
         }%
      }%
   }%
}{\end{mdframed}}

\newcommand\info[1][5ex]{%
  \renewcommand\stacktype{L}%
  \scaleto{\stackon[1.2pt]{\color{blue}$\bigcirc$}{\raisebox{-1.5pt}{\small i}}}{#1}%
}

\newenvironment{information}[1][]{%
   \begin{mdframed}[%
      backgroundcolor={blue!15}, hidealllines=true,
      skipabove=0.7\baselineskip, skipbelow=0.7\baselineskip,
      splitbottomskip=2pt, splittopskip=4pt, #1]%
   \makebox[0pt]{% ignore the withd of !
      \smash{% ignor the height of !
         %\fontsize{32pt}{32pt}\selectfont% make the ! bigger
         \hspace*{-45pt}% move ! to the left
         \raisebox{-5pt}{% move ! up a little
            {\info}% type the bold red !
         }%
      }%
   }%
}{\end{mdframed}}

\pgfdeclarelayer{background}
\pgfdeclarelayer{foreground}
\pgfsetlayers{background,main,foreground}

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

\usepackage{makecell}
\usepackage{hyperref}
\newcommand{\vna}{LibreVNA}

\title{LibreVNA Device Protocol\\\small{Version 13}}

\begin{document}
\maketitle
\tableofcontents
\clearpage

\section{Introduction}
This document describes the device protocol of the LibreVNA. This is the protocol used by the LibreVNA to communicate with the LibreVNA-GUI (or other custom implementations). In the context of this document, the LibreVNA is also referred to as the ``device'' and the LibreVNA-GUI as the ``host''.

\section{Hardware interface}
Depending on the LibreVNA, different hardware interfaces may be used for the implementation of this protocol.

\subsection{USB device}
The LibreVNA implements a ``custom class'' USB device. It uses a VID of 0x1209 and a PID of 0x4121. The custom class contains a single interface with three bulk endpoints:
\begin{itemize}
\item \textbf{Endpoint 0x01:} Communication data from the USB host to the LibreVNA
\item \textbf{Endpoint 0x81:} Communication data from the LibreVNA to the USB host
\item \textbf{Endpoint 0x82:} Debug messages from the LibreVNA
\end{itemize}

Endpoint 0x82 is exclusively used for debug messages. They are transmitted in ASCII format. All protocol packets described in this document are always transmitted over endpoints 0x01 and 0x81.

\subsection{Ethernet interface}
The ethernet interface implements two TCP servers, one for protocol data and one for debug messages:
\begin{itemize}
\item \textbf{Port 19544:} Data interface
\item \textbf{Port 19545:} Debug interface
\end{itemize}
Each server only supports a single connection. If another connection request is received, the existing connection is closed before accepting the new one.

Incoming data on the debug interface is ignored. Debug messages are transmitted in ASCII format. All protocol packets described in this document are always transmitted over the data interface.

\subsubsection{Device Discovery}
Initially, the IP addresses of connected LibreVNAs may not be known. To automatically detect any devices, the LibreVNA implements SSDP and responds to M-SEARCH packets looking for either
\begin{lstlisting}
ssdp:all
\end{lstlisting}
or
\begin{lstlisting}
urn:schemas-upnp-org:device:LibreVNA:1
\end{lstlisting}
services.

\section{General packet structure}
The data traffic can be viewed as a stream of bytes. The communication between the LibreVNA and the host is done in packets. To detect the packets within the data stream, some framing is needed. This general package structure is described in this section.

Each packet consists of the following fields:
\begin{enumerate}
\item \textbf{Header:} 1 byte, always 0x5A
\item \textbf{Length:} 2 bytes, length of the overall packet in bytes, including the header and the checksum
\item \textbf{Type:} 1 byte, defines the type of packet and subsequently the data encoding within the payload
\item \textbf{Payload:} Any amount of bytes, content depends on the packet type
\item \textbf{CRC:} 4 bytes, CRC32 over all other packet bytes (header, length, type and payload)
\end{enumerate}
\noindent
All values in the device protocol are little-endian.

\section{Packet types}
The following packet types are available:
\begin{ThreePartTable}
\setlength\tabcolsep{3pt}

\begin{TableNotes}
  \item[a] Direction of packet transfer:
  \begin{footnotesize}
  \begin{itemize}
  \item \textbf{D$\rightarrow$H:} Device to host
  \item \textbf{H$\rightarrow$D:} Host to device
  \item \textbf{D$\leftrightarrow$H:} Both directions used
  \end{itemize}
  \end{footnotesize}
  \item[b] Packet type that will be sent in response to this packet
  \item[c] The response will be sent multiple times
\end{TableNotes}

\begin{longtable}{p{0.06\textwidth} |  p{0.3\textwidth} | p{0.07\textwidth} | p{0.4\textwidth} |p{0.1\textwidth} }
\toprule
\textbf{Type} &\textbf{Name}  & \textbf{Dir}\tnote{a} &\textbf{Description} &\textbf{Answer}\tnote{a} \\ 
\hline
\endhead
\midrule[\heavyrulewidth]
\endfoot  
\midrule[\heavyrulewidth]
\insertTableNotes  % tell LaTeX where to insert the table-related notes
\endlastfoot

2 & SweepSettings & H$\rightarrow$D & Sets the sweep paramaters and starts the sweep in VNA mode& 27\tnote{c}\\
3 & ManualStatus & D$\rightarrow$H & Contains the hardware status when in manual control mode & None\\
4 & ManualControl & H$\rightarrow$D & Transfers the manual control configuration, switches the device into manual control mode & 3\tnote{c}\\
5 & DeviceInfo & D$\rightarrow$H & Contains the device information (firmware/hardware version, capabilities,...)&None \\
6 & FirmwarePacket & H$\rightarrow$D & Contains a piece of firmware data &None \\
7 & Ack & D$\rightarrow$H & Sent as a response to every successfully received and handled packet&None \\
8 & ClearFlash & H$\rightarrow$D & Triggers the flash erase procedure. Must be issues before transferring firmware data&None \\
9 & PerformFirmwareUpdate & H$\rightarrow$D & Triggers the firmware update once all firmware data has been transferred&None \\
10 & Nack & D$\rightarrow$H & Sent as a response to every unknown command or failure to execute the requested command&None \\
11 & Reference & H$\rightarrow$D & Configure the external/internal reference &None \\
12 & Generator & H$\rightarrow$D & Switches the VNA into generator mode and configures the generator output&None \\
13 & SpectrumAnalyzerSettings & H$\rightarrow$D & Sets the sweep parameters and starts the sweep in spectrum analyzer mode&14\tnote{c} \\
14 & SpectrumAnalyzerResult & D$\rightarrow$H & Sent for every sampled frequency within the sweep in spectrum analyzer mode&None \\
15 & RequestDeviceInfo & H$\rightarrow$D & Makes the device send the DeviceInfo packet &5 \\
16 & RequestSourceCal & H$\rightarrow$D & Makes the device send the source calibration packets & 18\tnote{c}\\
17 & RequestReceiverCal & H$\rightarrow$D & Makes the device send the receiver calibration packets & 19\tnote{c}\\
18 & SourceCalPoint & D$\leftrightarrow$H & Contains a single source amplitude calibration point &None\\
19 & ReceiverCalPoint & D$\leftrightarrow$H & Contains a single receiver amplitude calibration point &None \\
20 & SetIdle & H$\rightarrow$D & Stops all device activity & None \\
21 & RequestFrequencyCorrection & H$\rightarrow$D & Makes the device send the frequency calibration packet &22 \\
22 & FrequencyCorrection & D$\leftrightarrow$H & Contains the frequency calibration factor & None\\
23 & RequestDeviceConfig & H$\rightarrow$D & Makes the device send its device configuration & 24\\
24 & DeviceConfig & D$\rightarrow$H & Contains the configuration of various global device settings &None \\
25 & DeviceStatus & D$\rightarrow$H & Contains the hardware device status (lock, temperatures,...) &None \\
26 & RequestDeviceStatus & H$\rightarrow$D & Makes the device send the device status &25 \\
27 & VNADatapoint & D$\rightarrow$H & Sent for every sampled frequency within the sweep in VNA mode &None \\
28 & SetTrigger & D$\leftrightarrow$H & Updates the trigger status for synchronization over the data interface & None\\
29 & ClearTrigger & D$\leftrightarrow$H & Updates the trigger status for synchronization over the data interface & None\\
30 & StopStatusUpdates & H$\rightarrow$D & Stops the automatic transmission of device status packets & None\\
31 & StartStatusUpdates & H$\rightarrow$D & Starts the automatic transmission of device status packets & None\\
32 & InitiateSweep & H$\rightarrow$D & Initiates a single sweep when configured for standby operation & None\\
\end{longtable}   
\end{ThreePartTable}
An Ack is transmitted by the device for every received command after it has been handled successfully.

Received packets from the device are not acknowledged by the host; the host never sends an Ack packet.

\subsection{SweepSettings}
Transmitting this packet will switch the LibreVNA into VNA mode and start the sweep. During the sweep, VNADatapoint packets are generated for each completed point in the sweep.

The sampling for each frequency (or power) point in the sweep is done in stages. In each stage, the stimulus can be active at another port. A typical full two-port sweep would therefore use two stages, with the stimulus being active on port 1 during stage 0 and on port 2 during stage 1. For faster measurements, this could be reduced to a single stage if only a subset of the S-parameters is required. Similarly, more stages than the number of ports can be used (with the stimulus inactive during some) when multiple devices are synchronized. Another device in the setup will have to generate the stimulus during the inactive stages.

The packet contains the following fields:
\begin{ThreePartTable}
\setlength\tabcolsep{3pt}

\begin{longtable}{p{0.08\textwidth} |  p{0.08\textwidth}  |  p{0.1\textwidth}| p{0.25\textwidth} | p{0.43\textwidth}}
\toprule
\textbf{Offset} &\textbf{Length} &\textbf{Type} & \textbf{Name} &\textbf{Description} \\ 
\hline
\endhead
\midrule[\heavyrulewidth]
\endfoot  
\midrule[\heavyrulewidth]
%\insertTableNotes  % tell LaTeX where to insert the table-related notes
\endlastfoot

0 & 8 & UINT64 & f\_start & Start frequency in Hz \\
8 & 8 & UINT64 & f\_stop & Stop frequency in Hz \\
16 & 2 & UINT16 & points & Number of points in the sweep \\
18 & 4 & UINT32 & IF\_bandwidth & Bandwidth of the IF sampling in Hz \\
22 & 2 &  INT16 &cdbm\_excitation\_start &  Stimulus power at the first point in $\frac{1}{100}$dBm \\
24 & 1 & UINT8 & Configuration & Bitmap for configuration, see below \\
25 & 2 & UINT16 & Stages & Bitmap for stage configuration, see below \\
27 & 2 &  INT16 &cdbm\_excitation\_stop & Stimulus power at the last point in $\frac{1}{100}$dBm \\
\end{longtable}   
\end{ThreePartTable}

\paragraph{Configuration:}
\begin{center}
\begin{tikzpicture}
\bitrect{8}{8-\bit}
%\rwbits{0}{2}{syncMode}
%\rwbits{2}{3}{P2 Stage}
%\rwbits{5}{3}{P1 Stage}
%\rwbits{1}{3}{Stages}
\robits{0}{1}{}
\rwbits{1}{2}{syncMode}
\rwbits{3}{1}{LOG}
\rwbits{4}{1}{FP}
\rwbits{5}{1}{SP}
\rwbits{6}{1}{SM}
\rwbits{7}{1}{SO}
\end{tikzpicture}
\end{center}
\begin{itemize}
\item \textbf{syncMode:} Synchronization mode when multiple devices are used together
\begin{center}
\begin{tabular}{ c|c }
Setting & Synchronization\\
 \hline
00 & Disabled \\
01 & Protocol\\
10 & Reserved\\
11 & External trigger\\
\end{tabular}
\end{center}
\item \textbf{LOG:} Set for a logarithmic sweep (only for frequency, power adjustment during the sweep is always linear)
\item \textbf{FP:} Fixed power setting. This must be disabled for power sweeps (when  cdbm\_excitation\_start $\neq$  cdbm\_excitation\_stop)
\begin{center}
\begin{tabularx}{\textwidth}{ c|X }
Setting & Behavior\\
 \hline
0 & Attenuator setting is fixed during the sweep. This will result in inaccurate stimulus level but prevent discrete jumps in output power. \\
1 & Attenuator setting is changed during the sweep. This will result in more accurate stimulus level but also create discrete jumps in output power. \\
\end{tabularx}
\end{center}
\item \textbf{SP:} Suppress peaks. Recommended setting: always enabled.
\begin{center}
\begin{tabularx}{\textwidth}{ c|X }
Setting & Behavior\\
 \hline
0 & 2.LO is adjusted to compensate for limited frequency resolution in 1.LO. Slight decrease in maximum sweep speed. \\
1 & 2.LO is kept at its nominal value. Slightly faster sweep but this will result in peaks at frequencies where the 1.LO it too far off the ideal frequency. \\
\end{tabularx}
\end{center}
\item \textbf{SM:} Sync Master. Must be set to 1 at exactly one device when multiple devices are synchronized. Set to 0 when synchronization is disabled.
\item \textbf{SO:} Standby Operation. Indicates whether the VNA will begin sweep immediately, or wait in the configured state to be triggered manually by InitiateSweep packets. Standy operation allows for lower latency of intermittent single sweeps.
\begin{center}
\begin{tabularx}{\textwidth}{ c|X }
Setting & Behavior\\
 \hline
0 & VNA will begin sweep immediately and timeout to idle mode 1000ms after sweep is completed or 100ms after entering the halted state. \\
1 & VNA will wait in a configured state for InitiateSweep packets. The host application is responsible for putting the VNA into idle mode with a SetIdle packet.\\
\end{tabularx}
\end{center}
\end{itemize}

\paragraph{Stages:}
\begin{center}
\begin{tikzpicture}
\bitrect{16}{16-\bit}
\robits{0}{1}{}
\rwbits{1}{3}{P4 Stage}
\rwbits{4}{3}{P3 Stage}
\rwbits{7}{3}{P2 Stage}
\rwbits{10}{3}{P1 Stage}
\rwbits{13}{3}{Stages}
\end{tikzpicture}
\end{center}
\begin{itemize}
\item \textbf{P1 Stage:} Sets the stage number when the stimulus is active at port 1. Stage number indizes start at 0.
\item \textbf{P2 Stage:} Sets the stage number when the stimulus is active at port 2. Stage number indizes start at 0.
\item \textbf{P3 Stage:} Sets the stage number when the stimulus is active at port 3. Stage number indizes start at 0.
\item \textbf{P4 Stage:} Sets the stage number when the stimulus is active at port 4. Stage number indizes start at 0.
\item \textbf{Stages:} Sets the number of used stages. The number of stages is one more than this value. E.g. set to 1 for 2 stages
\end{itemize}

\subsection{ManualStatus}
This packet is generated by the LibreVNA when in manual control mode. It is transmitted in regular intervals on its own.

The content of this packet varies according to the hardware version reported in the DeviceInfo packet. Each hardware version sends a different ManualStatus packet according to the available hardware information. As the different content is implemented as a ``union'' in the protocol layer, the packet size always matches the largest content possible. For hardware versions whose content is smaller, the extra bytes can be ignored.

\subsubsection{Hardware Version 0x01}
The packet contains the following fields:
\begin{ThreePartTable}
\setlength\tabcolsep{3pt}

\begin{longtable}{p{0.08\textwidth} |  p{0.08\textwidth}  |  p{0.1\textwidth}| p{0.15\textwidth} | p{0.53\textwidth}}
\toprule
\textbf{Offset} &\textbf{Length} &\textbf{Type} & \textbf{Name} &\textbf{Description} \\ 
\hline
\endhead
\midrule[\heavyrulewidth]
\endfoot  
\midrule[\heavyrulewidth]
%\insertTableNotes  % tell LaTeX where to insert the table-related notes
\endlastfoot

0 & 2 & INT16 & port1min & Minimum value of the ADC at port 1 \\
2 & 2 & INT16 & port1max & Maximum value of the ADC at port 1 \\
4 & 2 & INT16 & port2min & Minimum value of the ADC at port 2 \\
6 & 2 & INT16 & port2max & Maximum value of the ADC at port 2 \\
8 & 2 & INT16 & refmin & Minimum value of the ADC at the reference receiver \\
10 & 2 & INT16 & refmax & Maximum value of the ADC at the reference receiver \\
12 & 4 & FLOAT & port1real & Real part of the complex signal at port 1 \\
16 & 4 & FLOAT & port1imag & Imaginary part of the complex signal at port 1 \\
20 & 4 & FLOAT & port2real & Real part of the complex signal at port 2 \\
24 & 4 & FLOAT & port2imag & Imaginary part of the complex signal at port 2 \\
28 & 4 & FLOAT & refreal & Real part of the complex signal at the reference receiver \\
32 & 4 & FLOAT & refimag & Imaginary part of the complex signal at the reference receiver \\
36 & 1 & UINT8 & temp\_source & Temperature of the source PLL in \si{\celsius} \\
37 & 1 & UINT8 & temp\_LO & Temperature of the LO PLL in \si{\celsius} \\
38 & 1 & UINT8 & Lock status & Bit 0: lock status of source PLL. Bit 1: lock status of LO PLL \\
\end{longtable}   
\end{ThreePartTable}

\subsubsection{Hardware Version 0xFF}
The packet contains the following fields:
\begin{ThreePartTable}
\setlength\tabcolsep{3pt}

\begin{longtable}{p{0.08\textwidth} |  p{0.08\textwidth}  |  p{0.1\textwidth}| p{0.15\textwidth} | p{0.53\textwidth}}
\toprule
\textbf{Offset} &\textbf{Length} &\textbf{Type} & \textbf{Name} &\textbf{Description} \\ 
\hline
\endhead
\midrule[\heavyrulewidth]
\endfoot  
\midrule[\heavyrulewidth]
%\insertTableNotes  % tell LaTeX where to insert the table-related notes
\endlastfoot

0 & 2 & INT16 & port1min & Minimum value of the ADC at port 1 \\
2 & 2 & INT16 & port1max & Maximum value of the ADC at port 1 \\
4 & 2 & INT16 & refmin & Minimum value of the ADC at the reference receiver \\
6 & 2 & INT16 & refmax & Maximum value of the ADC at the reference receiver \\
8 & 4 & FLOAT & port1real & Real part of the complex signal at port 1 \\
12 & 4 & FLOAT & port1imag & Imaginary part of the complex signal at port 1 \\
16 & 4 & FLOAT & refreal & Real part of the complex signal at the reference receiver \\
20 & 4 & FLOAT & refimag & Imaginary part of the complex signal at the reference receiver \\
24 & 1 & UINT8 & Lock status & Bit 0: lock status of source PLL. Bit 1: lock status of LO PLL \\
\end{longtable}   
\end{ThreePartTable}

\subsection{ManualControl}
This packet switches the LibreVNA to manual control mode. As long as the manual control mode is active, the LibreVNA will generate ManualStatus packets and send them to the host.

The content of this packet varies according to the hardware version reported in the DeviceInfo packet. Each hardware version expects a different ManualControl packet according to the available hardware information.

\subsubsection{Hardware Version 0x01}
The packet contains the following fields:
\begin{ThreePartTable}
\setlength\tabcolsep{3pt}

\begin{longtable}{p{0.08\textwidth} |  p{0.08\textwidth}  |  p{0.1\textwidth}| p{0.25\textwidth} | p{0.43\textwidth}}
\toprule
\textbf{Offset} &\textbf{Length} &\textbf{Type} & \textbf{Name} &\textbf{Description} \\ 
\hline
\endhead
\midrule[\heavyrulewidth]
\endfoot  
\midrule[\heavyrulewidth]
%\insertTableNotes  % tell LaTeX where to insert the table-related notes
\endlastfoot

0 & 1 & UINT8 & Source High Config & Configuration of the highband source \\
1 & 8 & UINT64 & Source High Frequency & Frequency of the highband source in Hz \\
9 & 1 & UINT8 & Source Low Config & Configuration of the lowband source \\
10 & 4 & UINT32 & Source Low Frequency & Frequency of the lowband source in Hz \\
14 & 2 & UINT16 & Source Path Config & Configuration of the source signal from the PLLs to the ports \\
16 & 1 & UINT8 & 1.LO Config & Configuration of the 1.LO \\
17 & 8 & UINT64 & 1.LO Frequency & Frequency of the 1.LO in Hz \\
25 & 1 & UINT8 & 2.LO Enable & Set to 1 to enable the 2.LO. Set to 0 to disable the 2.LO \\
26 & 4 & UINT32 & 2.LO Frequency & Frequency of the 2.LO in Hz \\
\hline
30 & 1 & UINT8 & Receiver enable & \makecell[l]{Bit 0: Enable port 1 receiver\\Bit 1: Enable port 1 receiver\\Bit 2: Enable reference receiver} \\
\hline
31 & 4 & UINT32 & Samples & Number of ADC samples for each complex wave calculation \\
32 & 1 & UINT8 & WindowType & Window selection for the complex wave calculation \\
\end{longtable}   
\end{ThreePartTable}

\paragraph{Source High Config:}
\begin{center}
\begin{tikzpicture}
\bitrect{8}{8-\bit}
\robits{0}{2}{}
\rwbits{2}{2}{LP}
\rwbits{4}{2}{Power}
\rwbits{6}{1}{RFEN}
\rwbits{7}{1}{CE}
\end{tikzpicture}
\end{center}

\begin{itemize}
\item \textbf{LP:} Lowpass setting
\begin{center}
\begin{tabular}{ c|c }
Setting & Cut-off frequency\\
 \hline
00 & \SI{947}{\mega\hertz} \\
01 &  \SI{1.88}{\giga\hertz}\\
10 & \SI{3.5}{\giga\hertz}\\
11 & No filter\\
\end{tabular}
\end{center}
\item \textbf{Power:} Power output of the highband source PLL
\begin{center}
\begin{tabular}{ c|c }
Setting & Power\\
 \hline
00 & \SI{-4}{\dBm} \\
01 & \SI{-1}{\dBm}\\
10 & \SI{2}{\dBm}\\
11 &  \SI{5}{\dBm}\\
\end{tabular}
\end{center}
\item \textbf{RFEN:} RF output enable
\item \textbf{CE:} Chip enable
\end{itemize}

\paragraph{Source Low Config:}
\begin{center}
\begin{tikzpicture}
\bitrect{8}{8-\bit}
\robits{0}{5}{}
\rwbits{5}{2}{Power}
\rwbits{7}{1}{EN}
\end{tikzpicture}
\end{center}

\begin{itemize}
\item \textbf{Power:} Power output of the lowband source PLL
\begin{center}
\begin{tabular}{ c|c }
Setting & Drive Strength\\
 \hline
00 & \SI{2}{\milli\ampere} \\
01 & \SI{4}{\milli\ampere}\\
10 & \SI{6}{\milli\ampere}\\
11 &  \SI{8}{\milli\ampere}\\
\end{tabular}
\end{center}
\item \textbf{EN:} Lowband source enable
\end{itemize}

\paragraph{Source Path Config:}
\begin{center}
\begin{tikzpicture}
\bitrect{16}{16-\bit}
\robits{0}{6}{}
\rwbits{6}{1}{PS}
\rwbits{7}{1}{AEN}
\rwbits{8}{1}{BS}
\rwbits{9}{7}{Attenuator}
\end{tikzpicture}
\end{center}

\begin{itemize}
\item \textbf{PS:} Port switch. Set to 1 to route the source signal to port 2, set to 0 to route the source signal to port 1.
\item \textbf{AEN:} Amplifier enable.
\item \textbf{PS:} Band select. Set to 1 to use the highband source, set to 0 to use the lowband source.
\item \textbf{Attenuator:} Attenuation of the source signal in \SI{0.25}{\dBm}.
\end{itemize}

\paragraph{1.LO Config:}
\begin{center}
\begin{tikzpicture}
\bitrect{8}{8-\bit}
\robits{0}{6}{}
\rwbits{6}{1}{RFEN}
\rwbits{7}{1}{CE}
\end{tikzpicture}
\end{center}

\begin{itemize}
\item \textbf{RFEN:} RF output enable
\item \textbf{CE:} Chip enable
\end{itemize}

\paragraph{WindowType:}
\begin{center}
\begin{tabular}{ c|c }
Setting & Window\\
 \hline
0 & None \\
1 & Kaiser\\
2 & Hann\\
3 & Flattop\\
\end{tabular}
\end{center}

\subsubsection{Hardware Version 0xFF}
The packet contains the following fields:
\begin{ThreePartTable}
\setlength\tabcolsep{3pt}

\begin{longtable}{p{0.08\textwidth} |  p{0.08\textwidth}  |  p{0.1\textwidth}| p{0.25\textwidth} | p{0.43\textwidth}}
\toprule
\textbf{Offset} &\textbf{Length} &\textbf{Type} & \textbf{Name} &\textbf{Description} \\ 
\hline
\endhead
\midrule[\heavyrulewidth]
\endfoot  
\midrule[\heavyrulewidth]
%\insertTableNotes  % tell LaTeX where to insert the table-related notes
\endlastfoot

0 & 1 & UINT8 & Source Config & Configuration of the source \\
1 & 8 & UINT64 & Source Frequency & Frequency of the source in Hz \\
9 & 1 & UINT8 & Source Path Config & Configuration of the source signal from the PLL to the port \\
10 & 1 & UINT8 & LO Config & Configuration of the LO \\
11 & 8 & UINT64 & LO Frequency & Frequency of the LO in Hz \\
19 & 2 & UINT16 & Acquisition Config & Configuration of the acquisition hardware \\
21 & 2 & UINT16 & Samples & Number of ADC samples for each complex wave calculation \\
\end{longtable}   
\end{ThreePartTable}

\paragraph{Source Config:}
\begin{center}
\begin{tikzpicture}
\bitrect{8}{8-\bit}
\robits{0}{3}{}
\rwbits{3}{3}{Power}
\rwbits{6}{1}{RFEN}
\rwbits{7}{1}{CE}
\end{tikzpicture}
\end{center}

\begin{itemize}
\item \textbf{Power:} Power output of the source PLL
\begin{center}
\begin{tabular}{ c|c }
Setting & Power\\
 \hline
000 & \SI{-1}{\dBm} \\
001 & \SI{+1}{\dBm}\\
010 & \SI{+2.5}{\dBm}\\
011 &  \SI{+3.5}{\dBm}\\
100 &  \SI{+4.5}{\dBm}\\
101 &  \SI{+5.5}{\dBm}\\
110 &  \SI{+6.5}{\dBm}\\
111 &  \SI{+7}{\dBm}\\
\end{tabular}
\end{center}
\item \textbf{RFEN:} RF output enable
\item \textbf{CE:} Chip enable
\end{itemize}

\paragraph{Source Path Config:}
\begin{center}
\begin{tikzpicture}
\bitrect{8}{8-\bit}
\rwbits{0}{1}{AEN}
\rwbits{1}{7}{Attenuator}
\end{tikzpicture}
\end{center}

\begin{itemize}
\item \textbf{AEN:} Amplifier enable.
\item \textbf{Attenuator:} Attenuation of the source signal in \SI{0.25}{\dBm}.
\end{itemize}

\paragraph{LO Config:}
\begin{center}
\begin{tikzpicture}
\bitrect{8}{8-\bit}
\robits{0}{4}{}
\rwbits{4}{1}{EXT}
\rwbits{5}{1}{AEN}
\rwbits{6}{1}{RFEN}
\rwbits{7}{1}{CE}
\end{tikzpicture}
\end{center}

\begin{itemize}
\item \textbf{EXT:} Use external LO input.
\item \textbf{AEN:} Amplifier enable.
\item \textbf{RFEN:} RF output enable
\item \textbf{CE:} Chip enable
\end{itemize}

\paragraph{Acquisition Config:}
\begin{center}
\begin{tikzpicture}
\bitrect{16}{16-\bit}
\robits{0}{4}{}
\rwbits{4}{4}{RefGain}
\rwbits{8}{4}{PortGain}
\rwbits{12}{2}{Window}
\rwbits{14}{1}{REN}
\rwbits{15}{1}{PEN}
\end{tikzpicture}
\end{center}
\begin{itemize}
\item \textbf{RefGain/PortGain:} Gain setting of the PGA in the frontend of the port or reference receiver.
\begin{center}
\begin{tabular}{ c|c }
Setting & Gain\\
 \hline
0 & 1 V/V \\
1 & 10 V/V\\
2 & 20 V/V\\
3 & 30 V/V\\
4 & 40 V/V\\
5 & 60 V/V\\
6 & 80 V/V\\
7 & 120 V/V\\
8 & 157 V/V\\
9 & 0.25 V/V\\
\end{tabular}
\end{center}
\item \textbf{Window:}
\begin{center}
\begin{tabular}{ c|c }
Setting & Window\\
 \hline
0 & None \\
1 & Kaiser\\
2 & Hann\\
3 & Flattop\\
\end{tabular}
\end{center}
\item \textbf{REN:} Reference receiver enable.
\item \textbf{PEN:} Port receiver enable.
\end{itemize}

\subsection{DeviceInfo}
This packet contains information about the connected device. It can be requested by sending a RequestDeviceInfo packet. This request is the first thing that should happen after the device has been enumerated to make sure the right protocol version is used.

The packet contains the following fields:
\begin{ThreePartTable}
\setlength\tabcolsep{3pt}

\begin{longtable}{p{0.08\textwidth} |  p{0.08\textwidth}  |  p{0.1\textwidth}| p{0.25\textwidth} | p{0.43\textwidth}}
\toprule
\textbf{Offset} &\textbf{Length} &\textbf{Type} & \textbf{Name} &\textbf{Description} \\ 
\hline
\endhead
\midrule[\heavyrulewidth]
\endfoot  
\midrule[\heavyrulewidth]
%\insertTableNotes  % tell LaTeX where to insert the table-related notes
\endlastfoot

0 & 2 & UINT16 & ProtocolVersion & Set to 13. If another value is reported, refer to the corresponding protocol description.\\
2 & 1 & UINT8 & FW\_major & Major firmware version \\
3 & 1 & UINT8 & FW\_minor & Minor firmware version \\
4 & 1 & UINT8 & FW\_patch & Patch of the firmware version \\
5 & 1 & UINT8 & hardware\_version & Version of the hardware, currently only  `1' \\
6 & 1 & CHAR & HW\_revision & Revision of the hardware, currently only `B' is used \\
7 & 8 & UINT64 & MinFreq & Minimum supported frequency in Hz \\
15 & 8 & UINT64 & MaxFreq & Maximum supported frequency in Hz \\
23 & 4 & UINT32 & MinIFBW & Minimum supported IF bandwidth in Hz \\
27 & 4 & UINT32 & MaxIFBW & Maximum supported IF bandwidth in Hz \\
31 & 2 & UINT16 & MaxPoints & Maximum number of points per sweep \\
33 & 2 & INT16 & MincdBm & Minimum stimulus power in $\frac{1}{100}$dBm \\
35 & 2 & INT16 & MaxcdBm & Maximum stimulus power in $\frac{1}{100}$dBm \\
37 & 4 & UINT32 & MinRBW & Minimum supported resolution bandwidth in Hz \\
41 & 4 & UINT32 & MaxRBW & Maximum supported resolution bandwidth in Hz \\
45 & 1 & UINT8 & MaxAmplitudePoints & Maximum supported number of amplitude calibration points \\
46 & 8 & UINT64 & MaxHarmonicFrequency & Maximum supported frequency when using harmonic mixing \\
54 & 1 & UINT8 & NumPorts & The number of frontend VNA ports the device supports \\
\end{longtable}   
\end{ThreePartTable}

\subsection{FirmwarePacket}
This packet contains a part of the firmware. When updating the firmware, this packet must be transmitted multiple times until the whole firmware has been transferred.

The packet contains the following fields:
\begin{ThreePartTable}
\setlength\tabcolsep{3pt}

\begin{longtable}{p{0.08\textwidth} |  p{0.08\textwidth}  |  p{0.1\textwidth}| p{0.25\textwidth} | p{0.43\textwidth}}
\toprule
\textbf{Offset} &\textbf{Length} &\textbf{Type} & \textbf{Name} &\textbf{Description} \\ 
\hline
\endhead
\midrule[\heavyrulewidth]
\endfoot  
\midrule[\heavyrulewidth]
%\insertTableNotes  % tell LaTeX where to insert the table-related notes
\endlastfoot

0 & 4 & UINT32 & Address & Address at which the firmware data starts\\
4 & 256 & UINT8 & Data & Binary firmware data \\
\end{longtable}   
\end{ThreePartTable}

\subsection{Ack}
This packet is sent by the device whenever a valid packet has been received. It has no payload.

\subsection{ClearFlash}
This packet must be sent before transferring the first piece of firmware data. It has no payload.

\subsection{PerformFirmwareUpdate}
This packet must be sent after the complete firmware data has been transmitted. It triggers the actual update process. The device will reboot during the update process. It has no payload.

\subsection{Nack}
This packet is sent by the device whenever an error occured while processing a received packet. It has no payload.

\subsection{Reference}
This packet is used to configure the external reference input and output.

The packet contains the following fields:
\begin{ThreePartTable}
\setlength\tabcolsep{3pt}

\begin{longtable}{p{0.08\textwidth} |  p{0.08\textwidth}  |  p{0.1\textwidth}| p{0.21\textwidth} | p{0.47\textwidth}}
\toprule
\textbf{Offset} &\textbf{Length} &\textbf{Type} & \textbf{Name} &\textbf{Description} \\ 
\hline
\endhead
\midrule[\heavyrulewidth]
\endfoot  
\midrule[\heavyrulewidth]
%\insertTableNotes  % tell LaTeX where to insert the table-related notes
\endlastfoot

0 & 4 & UINT32 & OutputFrequency & Frequency of the external reference output. Not every frequency can be reached by the PLL. Set to 0 to disable the reference output.\\
4 & 1 & UINT8 & ExternalInputConfig & \makecell[l]{Bit 0: Switch to external when signal detected\\Bit 1: Force usage of the external reference} \\
\end{longtable}   
\end{ThreePartTable}

\subsection{Generator}
This packet switches the LibreVNA into signal generator mode and configures the output signal.

The packet contains the following fields:
\begin{ThreePartTable}
\setlength\tabcolsep{3pt}

\begin{longtable}{p{0.08\textwidth} |  p{0.08\textwidth}  |  p{0.1\textwidth}| p{0.25\textwidth} | p{0.43\textwidth}}
\toprule
\textbf{Offset} &\textbf{Length} &\textbf{Type} & \textbf{Name} &\textbf{Description} \\ 
\hline
\endhead
\midrule[\heavyrulewidth]
\endfoot  
\midrule[\heavyrulewidth]
%\insertTableNotes  % tell LaTeX where to insert the table-related notes
\endlastfoot

0 & 8 & UINT64 & OutputFrequency & Output frequency of the generator in Hz\\
8 & 2 & INT16 & cdBmLevel & Output level in $\frac{1}{100}$dBm \\
10 & 1 & UINT8 & Configuration & Configuration bitmap, see below \\
\end{longtable}   
\end{ThreePartTable}

\paragraph{Configuration:}
\begin{center}
\begin{tikzpicture}
\bitrect{8}{8-\bit}
\robits{0}{4}{}
\rwbits{4}{1}{AC}
\rwbits{5}{3}{Port}
\end{tikzpicture}
\end{center}

\begin{itemize}
\item \textbf{AC:} Amplitude correction enable. If set to 1, the source amplitude calibration is used to reach better amplitude accuracy.
\item \textbf{Port:} Port selection:
\begin{center}
\begin{tabular}{ c|c }
Setting & Window\\
 \hline
0 & Disabled \\
1 & Output on port 1\\
2 & Output on port 2\\
3 & Output on port 3\\
4 & Output on port 4\\
\end{tabular}
\end{center}
\end{itemize}

\subsection{SpectrumAnalyzerSettings}
Transmitting this packet will switch the LibreVNA into spectrum analyzer mode and start the sweep. During the sweep, SpectrumAnalyzerResult packets are generated for each completed point in the sweep.

The packet contains the following fields:
\begin{ThreePartTable}
\setlength\tabcolsep{3pt}

\begin{longtable}{p{0.08\textwidth} |  p{0.08\textwidth}  |  p{0.1\textwidth}| p{0.25\textwidth} | p{0.43\textwidth}}
\toprule
\textbf{Offset} &\textbf{Length} &\textbf{Type} & \textbf{Name} &\textbf{Description} \\ 
\hline
\endhead
\midrule[\heavyrulewidth]
\endfoot  
\midrule[\heavyrulewidth]
%\insertTableNotes  % tell LaTeX where to insert the table-related notes
\endlastfoot

0 & 8 & UINT64 & f\_start & Start frequency in Hz \\
8 & 8 & UINT64 & f\_stop & Stop frequency in Hz \\
16 & 4 & UINT32 & RBW & Resolution bandwidth in Hz \\
20 & 2 & UINT16 & pointNum & Number of reported points in the sweep. The internally used number of points can be higher (depending on the RBW) \\
22 & 2 & UINT16 & Configuration & Bitmap for configuration, see below \\
24 & 8 & INT64 & TrackingOffset & Offset of the tracking generator in Hz \\
32 & 2 & INT16 & TrackingPower & Power of the tracking generator in $\frac{1}{100}$dBm \\
\end{longtable}   
\end{ThreePartTable}

\paragraph{Configuration:}
\begin{center}
\begin{tikzpicture}
\bitrect{16}{16-\bit}
\robits{0}{1}{}
\rwbits{1}{1}{SM}
\rwbits{2}{2}{syncMode}
\rwbits{4}{2}{TGP}
\rwbits{6}{1}{ASC}
\rwbits{7}{1}{TGE}
\rwbits{8}{1}{ARC}
\rwbits{9}{1}{DFT}
\rwbits{10}{3}{Detector}
\rwbits{13}{1}{SID}
\rwbits{14}{2}{Window}
\end{tikzpicture}
\end{center}
\begin{itemize}
\item \textbf{SM:} Sync Master. Must be set to 1 at exactly one device when multiple devices are synchronized. Set to 0 when synchronization is disabled.
\item \textbf{syncMode:} Synchronization mode when multiple devices are used together
\begin{center}
\begin{tabular}{ c|c }
Setting & Synchronization\\
 \hline
00 & Disabled \\
01 & Protocol\\
10 & Reserved\\
11 & External trigger\\
\end{tabular}
\end{center}
\item \textbf{TGP:} Tracking generator port. Port count starts at zero. E.g. set this to 1 for tracking generator active on port 2. Ignored if TGE is 0.
\item \textbf{ASC:} Apply source amplitude corrections. If enabled, the amplitude calibration is used to reach better accuracy of the tracking generator output.
\item \textbf{TGE:} Tracking generator enable.
\item \textbf{ARC:} Apply receiver amplitude corrections. If enabled, the amplitude calibration is used to reach better measurement accuracy.
\item \textbf{DFT:} Use DFT to speed up the acquisition. Can not be used when the tracking generator is enabled. Only useful for low resolution bandwidths.
\item \textbf{Detector:}
\begin{center}
\begin{tabular}{ c|c }
Setting & Detector type\\
 \hline
0 & Positive peak \\
1 & Negative peak \\
2 & Sample \\
3 & Normal \\
4 & Average \\
\end{tabular}
\end{center}
\item \textbf{SID:} Signal ID enable.
\item \textbf{Window:}
\begin{center}
\begin{tabular}{ c|c }
Setting & Window\\
 \hline
0 & None \\
1 & Kaiser\\
2 & Hann\\
3 & Flattop\\
\end{tabular}
\end{center}
\end{itemize}

\subsection{SpectrumAnalyzerResult}
This packet is transmitted by the LibreVNA for every point in the sweep when in spectrum analyzer mode.

The packet contains the following fields:
\begin{ThreePartTable}
\setlength\tabcolsep{3pt}

\begin{longtable}{p{0.08\textwidth} |  p{0.08\textwidth}  |  p{0.1\textwidth}| p{0.12\textwidth} | p{0.56\textwidth}}
\toprule
\textbf{Offset} &\textbf{Length} &\textbf{Type} & \textbf{Name} &\textbf{Description} \\ 
\hline
\endhead
\midrule[\heavyrulewidth]
\endfoot  
\midrule[\heavyrulewidth]
%\insertTableNotes  % tell LaTeX where to insert the table-related notes
\endlastfoot

0 & 4 & FLOAT & Port 1 & Voltage signal level at port 1 (1.0 equals \SI{1}{\milli\watt} into \SI{50}{\ohm})\\
4 & 4 & FLOAT & Port 2 & Voltage signal level at port 2 (1.0 equals \SI{1}{\milli\watt} into \SI{50}{\ohm})\\
8 & 4 & FLOAT & Port 3 & Voltage signal level at port 3 (1.0 equals \SI{1}{\milli\watt} into \SI{50}{\ohm})\\
12 & 4 & FLOAT & Port 4 & Voltage signal level at port 4 (1.0 equals \SI{1}{\milli\watt} into \SI{50}{\ohm})\\
16 & 8 & UINT64 & Frequency or Time & Frequency of the point (or time since beginning of SA mode if in zerospan) \\
24 & 2 & UINT16 & PointNum & Number of the point in the sweep \\
\end{longtable}   
\end{ThreePartTable}

\subsection{RequestDeviceInfo}
This packet is used to make the device send the DeviceInfo packet. It has no payload.

\subsection{RequestSourceCal}
This packet is used to make the device send the source amplitude calibration. It has no payload. For each source amplitude calibration point one SourceCalPoint packet will be returned.

\subsection{RequestReceiverCal}
This packet is used to make the device send the receiver amplitude calibration. It has no payload. For each receiver amplitude calibration point one ReceiverCalPoint packet will be returned.

\subsection{SourceCalPoint}
This packet contains one source calibration point. It can be transmitted in both directions. When reading the source calibration, it is transmitted from the device to the host. When writing the source calibration multiple of these packets are transferred from the host to the device. In both cases the packet for the point with the highest point number must be transmitted last.

The packet contains the following fields:
\begin{ThreePartTable}
\setlength\tabcolsep{3pt}

\begin{longtable}{p{0.08\textwidth} |  p{0.08\textwidth}  |  p{0.1\textwidth}| p{0.25\textwidth} | p{0.43\textwidth}}
\toprule
\textbf{Offset} &\textbf{Length} &\textbf{Type} & \textbf{Name} &\textbf{Description} \\ 
\hline
\endhead
\midrule[\heavyrulewidth]
\endfoot  
\midrule[\heavyrulewidth]
%\insertTableNotes  % tell LaTeX where to insert the table-related notes
\endlastfoot

0 & 1 & UINT8 & TotalPoints & Amount of total points in the amplitude calibration \\
1 & 1 & UINT8 & PointNum & Number of the calibration point contained in this packet \\
2 & 4 & UINT32 & Frequency & Frequency of the calibration point in \SI{10}{\hertz} \\
6 & 2 & INT16 & Port 1 & Correction value for port 1 in $\frac{1}{100}$dB \\
8 & 2 & INT16 & Port 2 & Correction value for port 2 in $\frac{1}{100}$dB \\
10 & 2 & INT16 & Port 3 & Correction value for port 3 in $\frac{1}{100}$dB \\
12 & 2 & INT16 & Port 4 & Correction value for port 4 in $\frac{1}{100}$dB \\
\end{longtable}   
\end{ThreePartTable}

\subsection{ReceiverCalPoint}
This packet contains one receiver calibration point. It can be transmitted in both directions. When reading the receiver calibration, it is transmitted from the device to the host. When writing the receiver calibration multiple of these packets are transferred from the host to the device. In both cases the packet for the point with the highest point number must be transmitted last.

The packet payload is identical to the SourceCalPoint packet.

\subsection{SetIdle}
This packet is used to stop any data acquisition from the LibreVNA. It has no payload.

\subsection{RequestFrequencyCorrection}
This packet is used to make the device send the FrequencyCorrection packet. It has no payload.

\subsection{FrequencyCorrection}
This packet contains the frequency correction factor for the internal reference. It can be transmitted in both directions. When reading the frequency correction, it is transmitted from the device to the host. When writing the frequency correction, it is transmitted from the host to the device.

The packet contains the following fields:
\begin{ThreePartTable}
\setlength\tabcolsep{3pt}

\begin{longtable}{p{0.08\textwidth} |  p{0.08\textwidth}  |  p{0.1\textwidth}| p{0.25\textwidth} | p{0.43\textwidth}}
\toprule
\textbf{Offset} &\textbf{Length} &\textbf{Type} & \textbf{Name} &\textbf{Description} \\ 
\hline
\endhead
\midrule[\heavyrulewidth]
\endfoot  
\midrule[\heavyrulewidth]
%\insertTableNotes  % tell LaTeX where to insert the table-related notes
\endlastfoot

0 & 4 & FLOAT & PPM & Error of the internal TCXO in ppm \\
\end{longtable}   
\end{ThreePartTable}

\subsection{RequestDeviceConfig}
This packet is used to make the device send the AcquisitionFrequencySettings packet. It has no payload.

\subsection{DeviceConfig}
This packet contains hardware specific configuration.

The content of this packet varies according to the hardware version reported in the DeviceInfo packet. Each hardware version sends a different DeviceConfig packet according to the available hardware information. As the different content is implemented as a ``union'' in the protocol layer, the packet size always matches the largest content possible. For hardware versions whose content is smaller, the extra bytes can be ignored.

These settings are at default values after the device has booted. It is normally not required to send this packet but changing these settings might be useful in special use cases. It can be transmitted in both directions. When reading the acquisition settings, it is transmitted from the device to the host. When writing the acquisition settings, it is transmitted from the host to the device.

\subsubsection{Hardware Version 0x01}
The packet contains the following fields:
\begin{ThreePartTable}
\setlength\tabcolsep{3pt}

\begin{longtable}{p{0.08\textwidth} |  p{0.08\textwidth}  |  p{0.1\textwidth}| p{0.25\textwidth} | p{0.43\textwidth}}
\toprule
\textbf{Offset} &\textbf{Length} &\textbf{Type} & \textbf{Name} &\textbf{Description} \\ 
\hline
\endhead
\midrule[\heavyrulewidth]
\endfoot  
\midrule[\heavyrulewidth]
%\insertTableNotes  % tell LaTeX where to insert the table-related notes
\endlastfoot

0 & 4 & UINT32 & 1.IF frequency & 1.IF frequency in Hz \\
4 & 1 & UINT8 & ADC prescaler & Prescaler used for the ADC sampling (refer to the FPGA protocol) \\
5 & 2 & UINT16 & DFT phase increment & Phase increment of the DFT between ADC samples (refer to the FPGA protocol). Together with the ADC prescaler it also sets the 2.IF frequency. \\
\end{longtable}   
\end{ThreePartTable}

\subsubsection{Hardware Version 0xFF}
The packet contains the following fields:
\begin{ThreePartTable}
\setlength\tabcolsep{3pt}

\begin{longtable}{p{0.08\textwidth} |  p{0.08\textwidth}  |  p{0.1\textwidth}| p{0.25\textwidth} | p{0.43\textwidth}}
\toprule
\textbf{Offset} &\textbf{Length} &\textbf{Type} & \textbf{Name} &\textbf{Description} \\ 
\hline
\endhead
\midrule[\heavyrulewidth]
\endfoot  
\midrule[\heavyrulewidth]
%\insertTableNotes  % tell LaTeX where to insert the table-related notes
\endlastfoot

0 & 4 & UINT32 & IP address\tnote{s} & IPv4 address in network byte order \\
4 & 4 & UINT32 & IP mask\tnote{s} & IPv4 mask in network byte order \\
8 & 4 & UINT32 & IP gateway\tnote{s} & IPv4 gateway address in network byte order \\
12 & 1 & UINT8 & DHCP\tnote{s} & 1 if DHCP is enabled, 0 otherwise \\
12 & 2 & UINT16 & Gain Config & Additional gain configuration bits, see below \\
\end{longtable}   
\begin{tablenotes}
\item[s] This parameter is stored on the device and retains its value after a reboot.
\end{tablenotes}
\end{ThreePartTable}

\paragraph{Gain Config:}
\begin{center}
\begin{tikzpicture}
\bitrect{16}{16-\bit}
\robits{0}{7}{}
\rwbits{7}{4}{RefGain}
\rwbits{11}{4}{PortGain}
\rwbits{15}{1}{AG}
\end{tikzpicture}
\end{center}
\begin{itemize}
\item \textbf{RefGain/PortGain:} Gain setting of the PGA in the frontend of the port or reference receiver.
\begin{center}
\begin{tabular}{ c|c }
Setting & Gain\\
 \hline
0 & 1 V/V \\
1 & 10 V/V\\
2 & 20 V/V\\
3 & 30 V/V\\
4 & 40 V/V\\
5 & 60 V/V\\
6 & 80 V/V\\
7 & 120 V/V\\
8 & 157 V/V\\
9 & 0.25 V/V\\
\end{tabular}
\end{center}
\item \textbf{AG:} Autogain. If set to 1, the gain values are ignored and the best PGA gain for each point is automatically determined while sweeping (reduces sweep speed).
\end{itemize}

\subsection{DeviceStatus}
This packet contains the status of the device. It can be requested by sending a RequestDeviceStatus packet. The device also sends this packet on its own. The interval in which this packet is sent depends on the currently active mode.

The content of this packet varies according to the hardware version reported in the DeviceInfo packet. Each hardware version sends a different DeviceStatus packet according to the available hardware information. As the different content is implemented as a ``union'' in the protocol layer, the packet size always matches the largest content possible. For hardware versions whose content is smaller, the extra bytes can be ignored.

\subsubsection{Hardware Version 0x01}
The packet contains the following fields:
\begin{ThreePartTable}
\setlength\tabcolsep{3pt}

\begin{longtable}{p{0.08\textwidth} |  p{0.08\textwidth}  |  p{0.1\textwidth}| p{0.25\textwidth} | p{0.43\textwidth}}
\toprule
\textbf{Offset} &\textbf{Length} &\textbf{Type} & \textbf{Name} &\textbf{Description} \\ 
\hline
\endhead
\midrule[\heavyrulewidth]
\endfoot  
\midrule[\heavyrulewidth]
%\insertTableNotes  % tell LaTeX where to insert the table-related notes
\endlastfoot

0 & 1 & UINT8 & StatusBits & Bitmap of various states. See below.\\
1 & 1 & UINT8 & temp\_source & Temperature of the source PLL in \si{\celsius} \\
2 & 1 & UINT8 & temp\_LO1 & Temperature of the 1.LO PLL in \si{\celsius} \\
3 & 1 & UINT8 & temp\_MCU & Temperature of the microcontroller in \si{\celsius} \\
\end{longtable}   
\end{ThreePartTable}

\paragraph{StatusBits:}
\begin{center}
\begin{tikzpicture}
\bitrect{8}{8-\bit}
\robits{0}{1}{}
\rwbits{1}{1}{ULV}
\rwbits{2}{1}{OVL}
\rwbits{3}{1}{LLO}
\rwbits{4}{1}{SLO}
\rwbits{5}{1}{FC}
\rwbits{6}{1}{ERU}
\rwbits{7}{1}{ERA}
\end{tikzpicture}
\end{center}
\begin{itemize}
\item \textbf{ULV:} Unlevel. The requested output signal amplitude can not be reached. This is not actually measured and based on calculations only.
\item \textbf{OVL:} ADC overload. The amplitude of at least one of the ADCs reached the non-linear region and the signal level can not be trusted.
\item \textbf{LLO:} 1.LO locked.
\item \textbf{SLO:} Source locked.
\item \textbf{FC:} FPGA successfully configured.
\item \textbf{ERU:} External reference used. The external reference input is used for all PLLs.
\item \textbf{ERA:} External reference available. A signal is detected at the external reference input.
\end{itemize}

\subsubsection{Hardware Version 0xFF}
The packet contains the following fields:
\begin{ThreePartTable}
\setlength\tabcolsep{3pt}

\begin{longtable}{p{0.08\textwidth} |  p{0.08\textwidth}  |  p{0.1\textwidth}| p{0.25\textwidth} | p{0.43\textwidth}}
\toprule
\textbf{Offset} &\textbf{Length} &\textbf{Type} & \textbf{Name} &\textbf{Description} \\ 
\hline
\endhead
\midrule[\heavyrulewidth]
\endfoot  
\midrule[\heavyrulewidth]
%\insertTableNotes  % tell LaTeX where to insert the table-related notes
\endlastfoot

0 & 1 & UINT8 & StatusBits & Bitmap of various states. See below.\\
1 & 1 & UINT8 & temp\_MCU & Temperature of the microcontroller in \si{\celsius} \\
\end{longtable}   
\end{ThreePartTable}

\paragraph{StatusBits:}
\begin{center}
\begin{tikzpicture}
\bitrect{8}{8-\bit}
\robits{0}{4}{}
\rwbits{4}{1}{ULV}
\rwbits{5}{1}{OVL}
\rwbits{6}{1}{LLO}
\rwbits{7}{1}{SLO}
\end{tikzpicture}
\end{center}
\begin{itemize}
\item \textbf{ULV:} Unlevel. The requested output signal amplitude can not be reached. This is not actually measured and based on calculations only.
\item \textbf{OVL:} ADC overload. The amplitude of at least one of the ADCs reached the non-linear region and the signal level can not be trusted.
\item \textbf{LLO:} 1.LO locked.
\item \textbf{SLO:} Source locked.
\end{itemize}

\subsection{RequestDeviceStatus}
This packet is used to make the device send the DeviceStatus packet. It has no payload.

\subsection{VNADatapoint}
The VNADatapoint packet is generated by the device for every completed sweep point when in VNA mode.
\begin{important}
This packet has the CRC set to 0x00000000 as the CRC calculation would take too long when using high IF bandwidths.
\end{important}

The packet contains the following fields:
\begin{ThreePartTable}
\setlength\tabcolsep{3pt}

\begin{longtable}{p{0.08\textwidth} |  p{0.08\textwidth}  |  p{0.1\textwidth}| p{0.25\textwidth} | p{0.43\textwidth}}
\toprule
\textbf{Offset} &\textbf{Length} &\textbf{Type} & \textbf{Name} &\textbf{Description} \\ 
\hline
\endhead
\midrule[\heavyrulewidth]
\endfoot  
\midrule[\heavyrulewidth]
%\insertTableNotes  % tell LaTeX where to insert the table-related notes
\endlastfoot

0 & 8 & UINT64 & Frequency & Frequency of the sweep point in Hz\\
8 & 2 & INT16 & PowerLevel & Stimulus level of the sweep point in $\frac{1}{100}$dBm \\
10 & 2 & UINT16 & PointNumber & Number of this point in the sweep \\
12 & 4*x & Array of FLOAT & Real values & The real parts of a variable amount of receiver data \\
12+4*x & 4*x & Array of FLOAT & Imag values & The imaginary parts of a variable amount of receiver data \\
12+8*x & 1*x & UINT8 & Array of UINT8 & Variable amount of data description bitmasks\\
\end{longtable}   
\end{ThreePartTable}

The sampling data consists of a variable amount of values. The amount of values depend on the amount of configured stages and also on the hardware architecture (might change in the future). The VNADatapoint contains three arrays of equal length. Two of the arrays contain the real and imaginary parts of the acquired data. The third array contains a bitmask for every value, describing the content. The length of all arrays is not explicitly transmitted and must be inferred from the overall packet length.

\paragraph{Data description bitmask:}
\begin{center}
\begin{tikzpicture}
\bitrect{8}{8-\bit}
\rwbits{0}{3}{Stage}
\rwbits{3}{1}{Ref}
\rwbits{4}{1}{P4}
\rwbits{5}{1}{P3}
\rwbits{6}{1}{P2}
\rwbits{7}{1}{P1}
\end{tikzpicture}
\end{center}
\begin{itemize}
\item \textbf{Stage:} The active stage when the value was acquired. The port on which the stimulus was active during this stage is known from the SweepSettings packet that was used to set up the currently active sweep.
\item \textbf{Ref:} The value is from a reference receiver.
\item \textbf{P4:} The value is from a port 4 receiver.
\item \textbf{P3:} The value is from a port 3 receiver.
\item \textbf{P2:} The value is from a port 2 receiver.
\item \textbf{P1:} The value is from a port 1 receiver.
\end{itemize}
In case of a three receiver architecture (as the LibreVNA 1.0 has), multiple port bits can be set for reference receiver values. For a typical full two-port sweep, the LibreVNA 1.0 will generate six values for every sweep point:
\begin{ThreePartTable}
\setlength\tabcolsep{3pt}

\begin{longtable}{p{0.08\textwidth} |  p{0.1\textwidth}  |  p{0.6\textwidth}}
\toprule
\textbf{\#} &\textbf{Bitmask} &\textbf{Content} \\ 
\hline
\endhead
\midrule[\heavyrulewidth]
\endfoot  
\midrule[\heavyrulewidth]
%\insertTableNotes  % tell LaTeX where to insert the table-related notes
\endlastfoot

1 & 0x01 & Port 1 receiver signal during stage 0 \\
2 & 0x02 & Port 2 receiver signal during stage 0 \\
3 & 0x13 & Reference receiver signal during stage 0 \\
4 & 0x21 & Port 1 receiver signal during stage 1 \\
5 & 0x22 & Port 2 receiver signal during stage 1 \\
6 & 0x33 & Reference receiver signal during stage 1 \\
\end{longtable}   
\end{ThreePartTable}

The host must assemble the S-parameter data from these receiver values. This calculation has to be offloaded to the host because the reference and port receiver measurements may be split across different devices when synchronizing multiple LibreVNAs.

\paragraph{Example procedure to assemble S21}
Some definitions and assumptions:
\begin{itemize}
\item S21 is the through measurement from port 1 to port 2, meaning we need the reference receiver data from port 1 and the port receiver data from port 2
\item Port 1 had the stimulus signal at stage 0 and port 2 had the stimulus signal at stage 1. This is the default for a full two-port sweep. If configured differently in the SweepSettings packet, adjust the stage values accordingly
\end{itemize}

\hfill\newline
The host must perform the following operations:
\begin{enumerate}
\item Wait for reception of a VNADatapoint packet
\item Determine the array length of the received data: $$array\_length = (packet\_size - 12) / 9$$ 
\item Find the port receiver data of port 2 for the correct stage (when port 1 had the stimulus, in this example stage 0)
\begin{enumerate}
\item Iterate over all data description bitmasks in the VNADatapoint
\item Find the one with bitmask 0b0000xx1x (stage 0, port 2, not a reference receiver measurement). Bits marked ``x'' are ``don't care''.
\item Note the index $n$ of this data description bitmask in the data description bitmask array
\item Use the index $n$ to get the real and imaginary values of the port receiver data from the real and imaginary arrays: $$port\_receiver = Real\_values[n] + i * Imag\_values[n]$$
\end{enumerate}
\item Find the reference receiver data of port 1 for the correct stage (when port 1 had the stimulus, in this example stage 0)
\begin{enumerate}
\item Iterate over all data description bitmasks in the VNADatapoint
\item Find the one with bitmask 0b0001xxx1 (stage 0, port 1, reference receiver measurement). Bits marked ``x'' are ``don't care''.
\item Note the index $n$ of this data description bitmask in the data description bitmask array
\item Use the index $n$ to get the real and imaginary values of the reference receiver data from the real and imaginary arrays: $$reference\_receiver = Real\_values[n] + i * Imag\_values[n]$$
\end{enumerate}
\item Calculate S21 as the ratio between the port and reference receiver data: $$ S21 = \frac{port\_receiver}{reference\_receiver}$$
\end{enumerate}

\subsection{SetTrigger}
This packet is used when multiple devices are synchronized over the data protocol and can be transmitted in both directions. It has no payload. Synchronized devices must be logically organized in a closed loop. When a SetTrigger packet is received from any devices in the loop it must be passed on to the next device in the loop.

\subsection{ClearTrigger}
This packet is used when multiple devices are synchronized over the data protocol and can be transmitted in both directions. It has no payload. Synchronized devices must be logically organized in a closed loop. When a ClearTrigger packet is received from any devices in the loop it must be passed on to the next device in the loop.

\subsection{StopStatusUpdates}
This packet instructs the device to stop sending automatically scheduled DeviceStatus packets. Device status can still be requested explicitly via RequestDeviceStatus packets.

\subsection{StartStatusUpdates}
This packet instructs the device to start sending automatically scheduled DeviceStatus packets. This restores default update behaviour if a StopStatusUpdates packet has previously been sent.

\subsection{InitiateSweep}
This packet instructs the device to initiate a new single sweep when the VNA is configured for standby operation. This triggering method can be used for fast intermittent single sweeps with minimum latency. If the SweepSettings are not configured for standby operation, this packet will result in a Nack response.

\end{document}

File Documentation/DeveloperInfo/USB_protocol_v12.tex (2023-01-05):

\documentclass[a4paper,11pt]{article}
\usepackage{titlesec}
\titleformat{\paragraph}
{\normalfont\normalsize\bfseries}{\theparagraph}{1em}{}
\titlespacing*{\paragraph}
{0pt}{3.25ex plus 1ex minus .2ex}{1.5ex plus .2ex}

\usepackage[utf8]{inputenc}
\usepackage[T1]{fontenc} % LY1 also works
\usepackage[margin=1in]{geometry}
\usepackage{tabularx}
%% Font settings suggested by fbb documentation.
\usepackage{textcomp} % to get the right copyright, etc.
\usepackage[lining,tabular]{fbb} % so math uses tabular lining figures
\usepackage[scaled=.95,type1]{cabin} % sans serif in style of Gill Sans
\usepackage[varqu,varl]{zi4}% inconsolata typewriter
\useosf % change normal text to use proportional oldstyle figures
%\usetosf would provide tabular oldstyle figures in text

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

\usepackage{booktabs,caption}
\usepackage{threeparttable}
\newcolumntype{L}[1]{>{\raggedright\let\newline\\\arraybackslash\hspace{0pt}}m{#1}}
\newcolumntype{C}[1]{>{\centering\let\newline\\\arraybackslash\hspace{0pt}}m{#1}}
\newcolumntype{R}[1]{>{\raggedleft\let\newline\\\arraybackslash\hspace{0pt}}m{#1}}
\usepackage{tabularx} 

\usepackage{multirow}
\usepackage{longtable,booktabs,threeparttablex}

\usepackage{stackengine}
\usepackage{scalerel}
\usepackage{xcolor,mdframed}

\newcommand\danger[1][5ex]{%
  \renewcommand\stacktype{L}%
  \scaleto{\stackon[1.3pt]{\color{red}$\triangle$}{\tiny !}}{#1}%
}

\newenvironment{important}[1][]{%
   \begin{mdframed}[%
      backgroundcolor={red!15}, hidealllines=true,
      skipabove=0.7\baselineskip, skipbelow=0.7\baselineskip,
      splitbottomskip=2pt, splittopskip=4pt, #1]%
   \makebox[0pt]{% ignore the withd of !
      \smash{% ignor the height of !
         %\fontsize{32pt}{32pt}\selectfont% make the ! bigger
         \hspace*{-45pt}% move ! to the left
         \raisebox{-5pt}{% move ! up a little
            {\danger}% type the bold red !
         }%
      }%
   }%
}{\end{mdframed}}

\newcommand\info[1][5ex]{%
  \renewcommand\stacktype{L}%
  \scaleto{\stackon[1.2pt]{\color{blue}$\bigcirc$}{\raisebox{-1.5pt}{\small i}}}{#1}%
}

\newenvironment{information}[1][]{%
   \begin{mdframed}[%
      backgroundcolor={blue!15}, hidealllines=true,
      skipabove=0.7\baselineskip, skipbelow=0.7\baselineskip,
      splitbottomskip=2pt, splittopskip=4pt, #1]%
   \makebox[0pt]{% ignore the withd of !
      \smash{% ignor the height of !
         %\fontsize{32pt}{32pt}\selectfont% make the ! bigger
         \hspace*{-45pt}% move ! to the left
         \raisebox{-5pt}{% move ! up a little
            {\info}% type the bold red !
         }%
      }%
   }%
}{\end{mdframed}}

\pgfdeclarelayer{background}
\pgfdeclarelayer{foreground}
\pgfsetlayers{background,main,foreground}

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

\usepackage{makecell}
\usepackage{hyperref}
\newcommand{\vna}{LibreVNA}

\title{LibreVNA USB Protocol\\\small{Version 12}}

\begin{document}
\maketitle
\tableofcontents
\clearpage

\section{USB device}
The LibreVNA implements a ``custom class'' USB device. It uses a VID of 0x0483 and a PID of 0x4121. The custom class contains a single interface with three bulk endpoints:
\begin{itemize}
\item \textbf{Endpoint 0x01:} Communication data from the USB host to the LibreVNA
\item \textbf{Endpoint 0x81:} Communication data from the LibreVNA to the USB host
\item \textbf{Endpoint 0x82:} Debug messages from the LibreVNA
\end{itemize}

Endpoint 0x82 is exclusively used for debug messages. They are transmitted in ASCII format. All protocol packets described in this document are always transmitted over endpoints 0x01 and 0x81.

\section{General packet structure}
The USB traffic through bulk endpoints can be viewed as a stream of bytes. The communication between the LibreVNA and the USB host is done in packets. To detect the packets within the data stream, some framing is needed. This general package structure is described in this section.

Each packet consists of the following fields:
\begin{enumerate}
\item \textbf{Header:} 1 byte, always 0x5A
\item \textbf{Length:} 2 bytes, length of the overall packet in bytes, including the header and the checksum
\item \textbf{Type:} 1 byte, defines the type of packet and subsequently the data encoding within the payload
\item \textbf{Payload:} Any amount of bytes, content depends on the packet type
\item \textbf{CRC:} 4 bytes, CRC32 over all other packet bytes (header, length, type and payload)
\end{enumerate}
\noindent
All values in the USB protocol are little-endian.

\section{Packet types}
The following packet types are available:
\begin{ThreePartTable}
\setlength\tabcolsep{3pt}

\begin{TableNotes}
  \item[a] Direction of packet transfer:
  \begin{footnotesize}
  \begin{itemize}
  \item \textbf{D$\rightarrow$H:} Device to host
  \item \textbf{H$\rightarrow$D:} Host to device
  \item \textbf{D$\leftrightarrow$H:} Both directions used
  \end{itemize}
  \end{footnotesize}
  \item[b] Packet type that will be sent in response to this packet
  \item[c] The response will be sent multiple times
\end{TableNotes}

\begin{longtable}{p{0.06\textwidth} |  p{0.3\textwidth} | p{0.07\textwidth} | p{0.4\textwidth} |p{0.1\textwidth} }
\toprule
\textbf{Type} &\textbf{Name}  & \textbf{Dir}\tnote{a} &\textbf{Description} &\textbf{Answer}\tnote{a} \\ 
\hline
\endhead
\midrule[\heavyrulewidth]
\endfoot  
\midrule[\heavyrulewidth]
\insertTableNotes  % tell LaTeX where to insert the table-related notes
\endlastfoot

2 & SweepSettings & H$\rightarrow$D & Sets the sweep paramaters and starts the sweep in VNA mode& 27\tnote{c}\\
3 & ManualStatusV1 & D$\rightarrow$H & Contains the hardware status when in manual control mode & None\\
4 & ManualControlV1 & H$\rightarrow$D & Transfers the manual control configuration, switches the device into manual control mode & 3\tnote{c}\\
5 & DeviceInfo & D$\rightarrow$H & Contains the device information (firmware/hardware version, capabilities,...)&None \\
6 & FirmwarePacket & H$\rightarrow$D & Contains a piece of firmware data &None \\
7 & Ack & D$\rightarrow$H & Sent as a response to every successfully received and handled packet&None \\
8 & ClearFlash & H$\rightarrow$D & Triggers the flash erase procedure. Must be issues before transferring firmware data&None \\
9 & PerformFirmwareUpdate & H$\rightarrow$D & Triggers the firmware update once all firmware data has been transferred&None \\
10 & Nack & D$\rightarrow$H & Sent as a response to every unknown command or failure to execute the requested command&None \\
11 & Reference & H$\rightarrow$D & Configure the external/internal reference &None \\
12 & Generator & H$\rightarrow$D & Switches the VNA into generator mode and configures the generator output&None \\
13 & SpectrumAnalyzerSettings & H$\rightarrow$D & Sets the sweep parameters and starts the sweep in spectrum analyzer mode&14\tnote{c} \\
14 & SpectrumAnalyzerResult & D$\rightarrow$H & Sent for every sampled frequency within the sweep in spectrum analyzer mode&None \\
15 & RequestDeviceInfo & H$\rightarrow$D & Makes the device send the DeviceInfo packet &5 \\
16 & RequestSourceCal & H$\rightarrow$D & Makes the device send the source calibration packets & 18\tnote{c}\\
17 & RequestReceiverCal & H$\rightarrow$D & Makes the device send the receiver calibration packets & 19\tnote{c}\\
18 & SourceCalPoint & D$\leftrightarrow$H & Contains a single source amplitude calibration point &None\\
19 & ReceiverCalPoint & D$\leftrightarrow$H & Contains a single receiver amplitude calibration point &None \\
20 & SetIdle & H$\rightarrow$D & Stops all device activity & None \\
21 & RequestFrequencyCorrection & H$\rightarrow$D & Makes the device send the frequency calibration packet &22 \\
22 & FrequencyCorrection & D$\leftrightarrow$H & Contains the frequency calibration factor & None\\
23 & RequestAcquisition-FrequencySettings & H$\rightarrow$D & Makes the device send the acquisition frequency settings & 24\\
24 & AcquisitionFrequencySettings & D$\rightarrow$H & Contains the configuration of IF and sample frequencies &None \\
25 & DeviceStatusV1 & D$\rightarrow$H & Contains the hardware device status (lock, temperatures,...) &None \\
26 & RequestDeviceStatus & H$\rightarrow$D & Makes the device send the device status &25 \\
27 & VNADatapoint & D$\rightarrow$H & Sent for every sampled frequency within the sweep in VNA mode &None \\
28 & SetTrigger & D$\leftrightarrow$H & Updates the trigger status for synchronization over USB & None\\
29 & ClearTrigger & D$\leftrightarrow$H & Updates the trigger status for synchronization over USB & None\\
30 & StopStatusUpdates & H$\rightarrow$D & Stops the automatic transmission of device status packets & None\\
31 & StartStatusUpdates & H$\rightarrow$D & Starts the automatic transmission of device status packets & None\\
32 & InitiateSweep & H$\rightarrow$D & Initiates a single sweep when configured for standby operation & None\\
\end{longtable}   
\end{ThreePartTable}
An Ack is transmitted by the device for every received command after it has been handled successfully. If additional responses are triggered by the command, they are transmitted after this Ack.

Received packets from the device are not acknowledged by the host; the host never sends an Ack packet.

\subsection{SweepSettings}
Transmitting this packet will switch the LibreVNA into VNA mode and start the sweep. During the sweep, VNADatapoint packets are generated for each completed point in the sweep.

The sampling for each frequency (or power) point in the sweep is done in stages. In each stage, the stimulus can be active at another port. A typical full two-port sweep would therefore use two stages, with the stimulus being active on port 1 during stage 0 and on port 2 during stage 1. For faster measurements, this could be reduced to a single stage if only a subset of the S-parameters is required. Similarly, more than two stages can be used (with the stimulus inactive during some) when multiple devices are synchronized. Another device in the setup will have to generate the stimulus during the inactive stages.

The packet contains the following fields:
\begin{ThreePartTable}
\setlength\tabcolsep{3pt}

\begin{longtable}{p{0.08\textwidth} |  p{0.08\textwidth}  |  p{0.1\textwidth}| p{0.25\textwidth} | p{0.43\textwidth}}
\toprule
\textbf{Offset} &\textbf{Length} &\textbf{Type} & \textbf{Name} &\textbf{Description} \\ 
\hline
\endhead
\midrule[\heavyrulewidth]
\endfoot  
\midrule[\heavyrulewidth]
%\insertTableNotes  % tell LaTeX where to insert the table-related notes
\endlastfoot

0 & 8 & UINT64 & f\_start & Start frequency in Hz \\
8 & 8 & UINT64 & f\_stop & Stop frequency in Hz \\
16 & 2 & UINT16 & points & Number of points in the sweep \\
18 & 4 & UINT32 & IF\_bandwidth & Bandwidth of the IF sampling in Hz \\
22 & 2 &  INT16 &cdbm\_excitation\_start &  Stimulus power at the first point in $\frac{1}{100}$dBm \\
24 & 2 & UINT16 & Configuration & Bitmap for configuration, see below \\
26 & 2 &  INT16 &cdbm\_excitation\_stop & Stimulus power at the last point in $\frac{1}{100}$dBm \\
\end{longtable}   
\end{ThreePartTable}

\paragraph{Configuration:}
\begin{center}
\begin{tikzpicture}
\bitrect{16}{16-\bit}
\rwbits{0}{2}{syncMode}
\rwbits{2}{3}{P2 Stage}
\rwbits{5}{3}{P1 Stage}
\rwbits{8}{3}{Stages}
\rwbits{11}{1}{LOG}
\rwbits{12}{1}{FP}
\rwbits{13}{1}{SP}
\rwbits{14}{1}{SM}
\rwbits{15}{1}{SO}
\end{tikzpicture}
\end{center}
\begin{itemize}
\item \textbf{syncMode:} Synchronization mode when multiple devices are used together
\begin{center}
\begin{tabular}{ c|c }
Setting & Synchronization\\
 \hline
00 & Disabled \\
01 & USB\\
10 & External reference\\
11 & External trigger\\
\end{tabular}
\end{center}
\item \textbf{P1 Stage:} Sets the stage number when the stimulus is active at port 1. Stage number indizes start at 0.
\item \textbf{P2 Stage:} Sets the stage number when the stimulus is active at port 2. Stage number indizes start at 0.
\item \textbf{Stages:} Sets the number of used stages. The number of stages is one more than this value. E.g. set to 1 for 2 stages
\item \textbf{LOG:} Set for a logarithmic sweep (only for frequency, power adjustment during the sweep is always linear)
\item \textbf{FP:} Fixed power setting. This must be enabled for power sweeps (when  cdbm\_excitation\_start $\neq$  cdbm\_excitation\_stop)
\begin{center}
\begin{tabularx}{\textwidth}{ c|X }
Setting & Behavior\\
 \hline
0 & Attenuator setting is fixed during the sweep. This will result in inaccurate stimulus level but prevent discrete jumps in output power. \\
1 & Attenuator setting is changed during the sweep. This will result in more accurate stimulus level but also create discrete jumps in output power. \\
\end{tabularx}
\end{center}
\item \textbf{SP:} Suppress peaks. Recommended setting: always enabled.
\begin{center}
\begin{tabularx}{\textwidth}{ c|X }
Setting & Behavior\\
 \hline
0 & 2.LO is adjusted to compensate for limited frequency resolution in 1.LO. Slight decrease in maximum sweep speed. \\
1 & 2.LO is kept at its nominal value. Slightly faster sweep but this will result in peaks at frequencies where the 1.LO it too far off the ideal frequency. \\
\end{tabularx}
\end{center}
\item \textbf{SM:} Sync Master. Must be set to 1 at exactly one device when multiple devices are synchronized. Set to 0 when synchronization is disabled.
\item \textbf{SO:} Standby Operation. Indicates whether the VNA will begin sweep immediately, or wait in the configured state to be triggered manually by InitiateSweep packets. Standy operation allows for lower latency of intermittent single sweeps.
\begin{center}
\begin{tabularx}{\textwidth}{ c|X }
Setting & Behavior\\
 \hline
0 & VNA will begin sweep immediately and timeout to idle mode 1000ms after sweep is completed or 100ms after entering the halted state. \\
1 & VNA will wait in a configured state for InitiateSweep packets. The host application is responsible for putting the VNA into idle mode with a SetIdle packet.\\
\end{tabularx}
\end{center}
\end{itemize}

\subsection{ManualStatusV1}
This packet is generated by the LibreVNA 1.0 when in manual control mode. It is transmitted in regular intervals on its own.

The packet contains the following fields:
\begin{ThreePartTable}
\setlength\tabcolsep{3pt}

\begin{longtable}{p{0.08\textwidth} |  p{0.08\textwidth}  |  p{0.1\textwidth}| p{0.15\textwidth} | p{0.53\textwidth}}
\toprule
\textbf{Offset} &\textbf{Length} &\textbf{Type} & \textbf{Name} &\textbf{Description} \\ 
\hline
\endhead
\midrule[\heavyrulewidth]
\endfoot  
\midrule[\heavyrulewidth]
%\insertTableNotes  % tell LaTeX where to insert the table-related notes
\endlastfoot

0 & 2 & INT16 & port1min & Minimum value of the ADC at port 1 \\
2 & 2 & INT16 & port1max & Maximum value of the ADC at port 1 \\
4 & 2 & INT16 & port2min & Minimum value of the ADC at port 2 \\
6 & 2 & INT16 & port2max & Maximum value of the ADC at port 2 \\
8 & 2 & INT16 & refmin & Minimum value of the ADC at the reference receiver \\
10 & 2 & INT16 & refmax & Maximum value of the ADC at the reference receiver \\
12 & 4 & FLOAT & port1real & Real part of the complex signal at port 1 \\
16 & 4 & FLOAT & port1imag & Imaginary part of the complex signal at port 1 \\
20 & 4 & FLOAT & port2real & Real part of the complex signal at port 2 \\
24 & 4 & FLOAT & port2imag & Imaginary part of the complex signal at port 2 \\
28 & 4 & FLOAT & refreal & Real part of the complex signal at the reference receiver \\
32 & 4 & FLOAT & refimag & Imaginary part of the complex signal at the reference receiver \\
36 & 1 & UINT8 & temp\_source & Temperature of the source PLL in \si{\celsius} \\
37 & 1 & UINT8 & temp\_LO & Temperature of the LO PLL in \si{\celsius} \\
38 & 1 & UINT8 & Lock status & Bit 0: lock status of source PLL. Bit 1: lock status of LO PLL \\
\end{longtable}   
\end{ThreePartTable}

\subsection{ManualControlV1}
This packet switches the LibreVNA to manual control mode. As long as the manual control mode is active, the LibreVNA will generate ManualStatusV1 packets and send them to the host.

The packet contains the following fields:
\begin{ThreePartTable}
\setlength\tabcolsep{3pt}
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

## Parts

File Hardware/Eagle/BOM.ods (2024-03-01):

Qty | Value | Parts | Device | Package | Comment
13 | 0 | R104, R105, R106, R107, R108, R109, R110, R176, R177, R178, R179, R180, R181 | R-EU_R0402 | R0402 | 0 Ohm 0402
10 | 100 | R7, R9, R164, R167, R169, R170, R171, R172, R174, R175 | R-EU_R0402 | R0402 | 100 Ohm, 0402, 1%
83 | 100n | C4, C6, C29, C31, C32, C33, C34, C48, C54, C55, C56, C57, C61, C62, C64, C69, C70, C72, C73, C75, C76, C77, C83, C84, C85, C86, C91, C94, C97, C98, C102, C103, C114, C115, C116, C117, C118, C119, C122, C132, C134, C135, C139, C140, C151, C152, C153, C154, C155, C156, C159, C169, C181, C182, C183, C185, C186, C190, C193, C199, C200, C201, C204, C205, C206, C207, C208, C209, C210, C211, C212, C213, C214, C215, C216, C217, C218, C219, C220, C221, C222, C269, C270 | C-EUC0402:2 | C0402 | 100n, 0402
15 | 100n/RF | C65, C68, C71, C74, C96, C99, C109, C110, C133, C136, C146, C147, C170, C178, C179 | C-EUC0402:2 | C0402 | 100n, 0402, broadband capacitor (e.g. ATC 530L series: ATC 530104KT16T)
51 | 100p | C9, C223, C224, C225, C226, C227, C228, C229, C230, C231, C232, C233, C234, C235, C236, C237, C238, C239, C240, C241, C242, C243, C244, C245, C246, C247, C248, C249, C250, C251, C252, C253, C254, C255, C256, C257, C258, C259, C260, C261, C262, C263, C264, C265, C266, C267, C268, C271, C272, C273, C274 | C-EUC0402:2 | C0402 | 100p, 0402, 25V
48 | 10k | R3, R5, R6, R11, R18, R19, R20, R21, R22, R23, R24, R25, R31, R116, R117, R121, R122, R125, R127, R128, R129, R130, R131, R132, R133, R143, R144, R145, R146, R147, R148, R149, R150, R151, R152, R153, R154, R155, R156, R157, R158, R159, R160, R161, R162, R163, R165, R166 | R-EU_R0402 | R0402 | 10k, 0402, 1%
24 | 10n | C5, C30, C39, C51, C80, C93, C104, C105, C106, C111, C120, C123, C141, C142, C143, C148, C157, C160, C171, C172, C175, C180, C191, C192 | C-EUC0402:2 | C0402 | 10n, 0402, 25V
17 | 10u | C1, C2, C3, C7, C8, C10, C11, C12, C13, C14, C15, C16, C17, C49, C53, C78, C82 | C-EUC1206 | C1206 | 10u, 1206, 10V
1 | 10u | L11 | INDUCTOR | INDC2012X100N | 10u, 0805
3 | 120p | C124, C161, C194 | C-EUC0402:2 | C0402 | 120p, 0402, 25V
3 | 150p | C128, C165, C196 | C-EUC0402:2 | C0402 | 150p, 0402, 25V
3 | 180p | C43, C63, C90 | C-EUC0402:2 | C0402 | 180p, 0402, 25V
2 | 18p | C67, C95 | C-EUC0402:2 | C0402 | 18p, 0402, 25V
3 | 1k | R60, R87, R101 | R-EU_R0402 | R0402 | 1k, 0402, 1%
2 | 1k8 | R15, R36 | R-EU_R0402 | R0402 | 1k8, 0402, 1%
21 | 1u | C58, C59, C60, C87, C88, C89, C100, C101, C108, C129, C131, C137, C138, C145, C166, C168, C177, C195, C198, C202, C203 | C-EUC0402:2 | C0402 | 1u, 0402, 6V3
11 | 1u | C18, C19, C20, C21, C26, C27, C28, C50, C52, C79, C81 | C-EUC0603:1 | C0603 | 1u, 0603, 16V
9 | 20 | R64, R65, R91, R92, R118, R119, R123, R124, R126 | R-EU_R0402 | R0402 | 20 Ohm, 0402, 1%
18 | 220 | R53, R54, R58, R59, R61, R62, R80, R81, R85, R86, R88, R89, R96, R97, R98, R99, R102, R103 | R-EU_R0402 | R0402 | 220 Ohm, 0402, 1%
2 | 2R7 | R26, R29 | R-EU_R0402 | R0402 | 2.7 Ohm, 0402, 1%
5 | 2u2 | L1, L2, L3, L4, L5 | SRN5040 | SRN5040 | SRN5040-2R2Y
12 | 330 | R17, R39, R120, R134, R135, R136, R137, R138, R139, R140, R141, R142 | R-EU_R0402 | R0402 | 330, 0402, 1%
15 | 330n | L14, L18, L24, L30, L31, L32, L33, L38, L39, L40, L41, L46, L47, L52, L53 | INDUCTOR0402 | L0402 | LQW15CNR33J10D
12 | 330p | C121, C125, C126, C127, C158, C162, C163, C164, C184, C187, C188, C189 | C-EUC0402:2 | C0402 | 330p, 0402, 25V
6 | 33n | L36, L37, L44, L45, L50, L51 | INDUCTOR0402 | L0402 | LQW15AN33NJ00D
3 | 33p | C130, C167, C197 | C-EUC0402:2 | C0402 | 33p, 0402, 25V
1 | 38k3 | R4 | R-EU_R0402 | R0402 | 38k3, 0402, 1%
2 | 3n3 | C66, C92 | C-EUC0402:2 | C0402 | 3n3, 0402, 25V
1 | 402 | R27 | R-EU_R0402 | R0402 | 402 Ohm, 0402, 1%
14 | 49R9 | R12, R13, R14, R32, R33, R34, R35, R38, R45, R46, R50, R72, R73, R76 | R-EU_R0402 | R0402 | 49R9, 0402, 1%
3 | 4k7 | R2, R94, R95 | R-EU_R0402 | R0402 | 4k7, 0402, 1%
4 | 4u7 | C22, C23, C24, C25 | C-EUC0603:1 | C0603 | 4u7, 0604, 10V
5 | 56 | R28, R63, R66, R90, R93 | R-EU_R0402 | R0402 | 56 Ohm, 0402, 1%
2 | 56p | C38, C47 | C-EUC0402:2 | C0402 | 56p, 0402, 25V
2 | 5k1 | R10, R30 | R-EU_R0402 | R0402 | 5k1, 0402, 1%
1 | 62 | R8 | R-EU_R0402 | R0402 | 62 Ohm, 0402, 1%
1 | 620 | R1 | R-EU_R0402 | R0402 | 620 Ohm, 0402, 1%
6 | 68n | L34, L35, L42, L43, L48, L49 | INDUCTOR0402 | L0402 | LQW15AN68NJ00D
1 | 6SLX9TQG144 | U2 | 6SLX9TQG144 | TQ144 | XC6SLX9-2TQG144
4 | 6k8 | R55, R56, R82, R83 | R-EU_R0402 | R0402 | 6k8, 0402, 1%
2 | 75 | R168, R173 | R-EU_R0402 | R0402 | 75 Ohm, 0402, 1%
2 | 82 | R16, R37 | R-EU_R0402 | R0402 | 82 Ohm, 0402, 1%
3 | ADL5801 | IC24, IC29, IC33 | ADL5801 | QFN50P400X400X100-25T250N | ADL5801
2 | AP2114H | IC8, IC19 | AP2114H | SOT230P700X180-4 | AP2114H-3.3TRG1
3 | B012-617DB-1-63-B331 | T1, T2, T3 | B012-617DB-1-63-B331 | EASTEVER_BALUN | B012-617DB-1-63-B331, third coil (tertiary wiring) removed
2 | AMPHENOL_132289 | AMPHENOL_132289 | AMPHENOL_132289 | Amphenol 132289 or similar
18 | DNP | C35, C36, C37, C40, C41, C42, C44, C45, C46, C107, C112, C113, C144, C149, C150, C173, C174, C176 | C-EUC0402:2 | C0402 | Do not place
2 | DNP | R47, R48 | PAT0816-C-3DB-T5 | PAT0816 | Do not place
1 | DNP | JP1 | PINHD-1X10/90 | 1X10/90 | Do not place
1 | DNP | JP2 | PINHD-2X10 | 2X10 | Do not place
8 | DNP | R57, R84, R100, R111, R112, R113, R114, R115 | R-EU_R0402 | R0402 | Do not place
1 | DSB221SDN/26MHz | Y1 | KXO-TCXO-CMOS-86 | 2.5X2.0_KXO-86-TCXO | DSB221SDN 26MHz
32 | Ferrite | L6, L7, L8, L9, L10, L12, L13, L15, L16, L17, L19, L20, L21, L22, L23, L25, L26, L27, L28, L29, L54, L55, L56, L57, L58, L59, L60, L61, L62, L63, L64, L65 | FERRITE | R0402 | BLM15AX601SN1
6 | Green | LED2, LED6, LED7, LED8, LED9, LED10 | LEDCHIPLED_0603 | CHIPLED_0603 | Generic green 0603 LED
4 | LDL212PU50R | IC3, IC4, IC5, IC6 | LDL212PU50R | SON95P300X300X100-7T170X240N | LDL212PU50R
1 | LM3370SD-4221 | IC2 | LM3370 | SON50P400X500X80-17T260X400N | LM3370SD-4221
1 | LP0603A0947ANTR | LP1 | LP0603A | FILTRDFN160X84X70-4N | LP0603A0947ANTR
1 | LP0603A1880ANTR | LP3 | LP0603A | FILTRDFN160X84X70-4N | LP0603A1880ANTR
1 | LP0603N3500ANTR | LP2 | LP0603A | FILTRDFN160X84X70-4N | LP0603N3500ANTR
3 | LT5560 | IC22, IC27, IC36 | LT5560 | SON50P300X300X80-9T165X238 | LT5560EDD
2 | MAX2871 | IC10, IC21 | MAX2871 | QFN50P500X500X80-33T310 | MAX2871ETJ+
1 | MBRS2040LT3G | D1 | D-SMB | SMB | MBRS2040LT3G
3 | MCP33131D-10-E/MS | IC26, IC31, IC35 | MCP33131D-10-E/MS | SOP50P490X110-10N | MCP33131D-10-E/MS
1 | MIC2253 | IC1 | MIC2253 | SON50P300X300X90-13T170X240N | MIC2253-06YML
3 | NCP702-1.8 | IC25, IC30, IC34 | NCP702 | SOT95P240X110-5 | NCP702SN18T1G
2 | NCP702-3.3 | IC9, IC20 | NCP702 | SOT95P240X110-5 | NCP702SN33T1G
2 | PAT0816-C-3DB-T5 | R40, R49 | PAT0816-C-3DB-T5 | PAT0816 | PAT0816-C-3DB-T5
1 | PJ-014D | J1 | PJ-014D | PJ-014D | CUI Devices PJ-014D
4 | QPC6324 | IC13, IC16, IC17, IC18 | QPC6324 | QFN50P400X400X75-21T206 | QPC6324SR
1 | RFSA3714 | IC14 | RFSA3714 | QFN50P400X400X75-25T270 | RFSA3714TR13
2 | RFSW6042 | IC11, IC12 | RFSW6042 | QFN40P180X180X55-13T76N | RFSW6042TR7
4 | Red | LED1, LED3, LED4, LED5 | LEDCHIPLED_0603 | CHIPLED_0603 | Generic red 0603 LED
1 | SI5351C | IC7 | SI5351C | QFN50P400X400X90-21T270N | SI5351C-B-GM
2 | SMA_CONNECTOR | X1, X2 | SMA_CONNECTOR | J502-ND-142-0711-821/826 | Generic SMA connector
2 | SSM3J338R | Q1, Q2 | SSM3J338R | SOTFL95P240X80-3N | SSM3J338R
1 | STM32G431CB | IC37 | STM32G431CB | QFN50P700X700X60-49T560N | STM32G431CBU6
3 | THS4521IDGKR | IC23, IC28, IC32 | THS4521IDGKR | SOP65P490X110-8N | THS4521IDGKR
19 | TPB1,27 | TP1, TP2, TP3, TP4, TP5, TP6, TP7, TP8, TP9, TP10, TP11, TP12, TP13, TP14, TP15, TP16, TP17, TP18, TP19 | TPB1,27 | B1,27 | Do not place
1 | TRF37A73 | IC15 | TRF37A73 | SON50P200X200X80-9T90X160N | TRF37A73IDSGR
1 | TYPE-C16P(073) | J4 | TYPE-C16P(073) | TYPE-C16P | LCSC C668624
1 | W25Q16BVSN | U1 | W25Q16BVSN | SO08 | W25Q16JL
Non PCB components:
1 | Top cover |  |  |  | Custom machined aluminium, see TopShield.step. All holes tapped with M3x0.5mm at least 3.4mm deep
1 | Bottom cover |  |  |  | Custom machined aluminium, see BottomShield.step.
21 | Screw |  |  |  | DIN912 M3x0.5mm, 8mm length
5 | Thermal adhesive pad |  |  |  | Roughly 5x5x0.5mm, attached to the top of IC24, IC29, IC33, IC10, IC21
1 | Power supply |  |  |  | 5V 2A with 3.4mm (1.3mm center pin) barrel jack connector (center pin is the positive rail)

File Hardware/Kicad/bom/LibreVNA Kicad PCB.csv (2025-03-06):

null | Sourced | Placed | References | Value | Footprint | Quantity
1 | ✓ | ✓ | C4, C6, C29, C31, C32, C33, C34, C48, C54, C55, C56, C57, C61, C62, C64, C69, C70, C72, C73, C75, C76, C77, C83, C84, C85, C86, C91, C94, C97, C98, C102, C103, C114, C115, C116, C117, C118, C119, C122, C132, C134, C135, C139, C140, C151, C152, C153, C154, C155, C156, C159, C169, C181, C182, C183, C185, C186, C190, C193, C199, C200, C201, C204, C205, C206, C207, C208, C209, C210, C211, C212, C213, C214, C215, C216, C217, C218, C219, C220, C221, C222, C269, C270 | 100nF | C_0402_1005Metric | 83
2 | ✓ | ✓ | C9, C223, C224, C225, C226, C227, C228, C229, C230, C231, C232, C233, C234, C235, C236, C237, C238, C239, C240, C241, C242, C243, C244, C245, C246, C247, C248, C249, C250, C251, C252, C253, C254, C255, C256, C257, C258, C259, C260, C261, C262, C263, C264, C265, C266, C267, C268, C271, C272, C273, C274 | 100pF | C_0402_1005Metric | 51
3 | ✓ | ✓ | C5, C30, C39, C51, C80, C93, C104, C105, C106, C111, C120, C123, C141, C142, C143, C148, C157, C160, C171, C172, C175, C180, C191, C192 | 10nF | C_0402_1005Metric | 24
4 | ✓ | ✓ | C58, C59, C60, C87, C88, C89, C100, C101, C108, C129, C131, C137, C138, C145, C166, C168, C177, C195, C198, C202, C203 | 1uF | C_0402_1005Metric | 21
5 | ✓ | ✓ | C35, C36, C37, C40, C41, C42, C44, C45, C46, C107, C112, C113, C144, C149, C150, C173, C174, C176 | DNP | C_0402_1005Metric | 18
6 | ✓ | ✓ | C1, C2, C3, C7, C8, C10, C11, C12, C13, C14, C15, C16, C17, C49, C53, C78, C82 | 10uF | C_1206_3216Metric | 17
7 | ✓ |  | C65, C68, C71, C74, C96, C99, C109, C110, C133, C136, C146, C147, C170, C178, C179 | 100nF/RF | C_0402_1005Metric | 15
8 | ✓ | ✓ | C121, C125, C126, C127, C158, C162, C163, C164, C184, C187, C188, C189 | 330pF | C_0402_1005Metric | 12
9 | ✓ | ✓ | C18, C19, C20, C21, C26, C27, C28, C50, C52, C79, C81 | 1uF | C_0603_1608Metric | 11
10 | ✓ | ✓ | C22, C23, C24, C25 | 4u7F | C_0603_1608Metric | 4
11 | ✓ | ✓ | C43, C63, C90 | 180pF | C_0402_1005Metric | 3
12 | ✓ | ✓ | C124, C161, C194 | 120pF | C_0402_1005Metric | 3
13 | ✓ | ✓ | C128, C165, C196 | 150pF | C_0402_1005Metric | 3
14 | ✓ | ✓ | C130, C167, C197 | 33pF | C_0402_1005Metric | 3
15 | ✓ | ✓ | C38, C47 | 56pF | C_0402_1005Metric | 2
16 | ✓ | ✓ | C66, C92 | 3n3F | C_0402_1005Metric | 2
17 | ✓ | ✓ | C67, C95 | 18pF | C_0402_1005Metric | 2
18 | ✓ | ✓ | R3, R5, R6, R11, R18, R19, R20, R21, R22, R23, R24, R25, R31, R69, R116, R117, R121, R122, R125, R127, R128, R129, R130, R131, R132, R133, R143, R144, R145, R146, R147, R148, R149, R150, R151, R152, R153, R154, R155, R156, R157, R158, R159, R160, R161, R162, R163, R165 | 10k | R_0402_1005Metric | 48
19 | ✓ | ✓ | R53, R54, R58, R59, R61, R62, R80, R81, R85, R86, R88, R89, R96, R97, R98, R99, R102, R103 | 220R | R_0402_1005Metric | 18
20 | ✓ | ✓ | R12, R13, R14, R32, R33, R34, R35, R38, R45, R46, R50, R72, R73, R76 | 49.9R | R_0402_1005Metric | 14
21 | ✓ | ✓ | R41, R42, R43, R44, R51, R52, R104, R105, R106, R107, R108, R109, R110 | 0R | R_0402_1005Metric | 13
22 | ✓ | ✓ | R17, R39, R120, R134, R135, R136, R137, R138, R139, R140, R141, R142 | 330R | R_0402_1005Metric | 12
23 | ✓ | ✓ | R7, R9, R67, R68, R70, R74, R75, R78, R79, R164 | 100R | R_0402_1005Metric | 10
24 | ✓ | ✓ | R64, R65, R91, R92, R118, R119, R123, R124, R126 | 20R | R_0402_1005Metric | 9
25 | ✓ | ✓ | R57, R84, R100, R111, R112, R113, R114, R115 | DNP | R_0402_1005Metric | 8
26 | ✓ | ✓ | R28, R63, R66, R90, R93 | 56R | R_0402_1005Metric | 5
27 | ✓ |  | R40, R47, R48, R49 | PAT0816-C-3DB-T5 | PAT0816 | 4
28 | ✓ | ✓ | R55, R56, R82, R83 | 6.8k | R_0402_1005Metric | 4
29 | ✓ | ✓ | R2, R94, R95 | 4.7k | R_0402_1005Metric | 3
30 | ✓ | ✓ | R60, R87, R101 | 1k | R_0402_1005Metric | 3
31 | ✓ | ✓ | R10, R30 | 5.1k | R_0402_1005Metric | 2
32 | ✓ | ✓ | R15, R36 | 1.8k | R_0402_1005Metric | 2
33 | ✓ | ✓ | R16, R37 | 82R | R_0402_1005Metric | 2
34 | ✓ | ✓ | R26, R29 | 2.7R | R_0402_1005Metric | 2
35 | ✓ | ✓ | R168, R173 | 75R | R_0402_1005Metric | 2
36 | ✓ | ✓ | R1 | 620R | R_0402_1005Metric | 1
37 | ✓ |  | R4 | 38.3k | R_0402_1005Metric | 1
38 | ✓ | ✓ | R8 | 62R | R_0402_1005Metric | 1
39 | ✓ | ✓ | R27 | 402R | R_0402_1005Metric | 1
40 | ✓ | ✓ | L6, L7, L8, L9, L10, L12, L13, L15, L16, L17, L19, L20, L21, L22, L23, L25, L26, L27, L28, L29, L54, L55, L56, L57, L58, L59, L60, L61, L62, L63, L64, L65 | FERRITE | R_0402_1005Metric | 32
41 | ✓ |  | L14, L18, L24, L30, L31, L32, L33, L38, L39, L40, L41, L46, L47, L52, L53 | 330nH | L_0402_1005Metric | 15
42 |  |  | L34, L35, L42, L43, L48, L49 | 68nH | L_0402_1005Metric | 6
43 | ✓ | ✓ | L36, L37, L44, L45, L50, L51 | 33nH | L_0402_1005Metric | 6
44 | ✓ |  | L1, L2, L3, L4, L5 | 2.2uH | L_Sunlord_SWPA5040S | 5
45 | ✓ |  | L11 | 10uH | L_0805_2012Metric_Pad1.15x1.40mm_HandSolder | 1
46 | ✓ |  | D1 | MBRS2040LT3G | D_SMB | 1
47 | ✓ |  | U1 | W25Q16BVSN | SOIC-8_3.9x4.9mm_P1.27mm | 1
48 | ✓ |  | U2 | XC6SLX9-TQG144 | TQFP-144_20x20mm_P0.5mm | 1
49 | ✓ |  | Y1 | 26MHz | Oscillator_SMD_ECS_20CSMV4_2.0x1.6mm | 1
50 | ✓ |  | X1, X2 | SMA | J502-ND-142-0711-821_826 | 2
51 | ✓ |  | LED2, LED6, LED7, LED8, LED9, LED10 | Green | LED_0603_1608Metric | 6
52 | ✓ |  | IC3, IC4, IC5, IC6 | LDL212PU50R | WSON-6-1EP_3x3mm_P0.95mm | 4
53 | ✓ |  | IC13, IC16, IC17, IC18 | QPC6324 | QFN-20-1EP_4x4mm_P0.5mm_EP2.5x2.5mm | 4
54 | ✓ |  | LED1, LED3, LED4, LED5 | Red | LED_0603_1608Metric | 4
55 | ✓ |  | IC22, IC27, IC36 | LT5560 | WSON-8-1EP_3x3mm_P0.5mm_EP1.45x2.4mm | 3
56 | ✓ |  | IC23, IC28, IC32 | THS4521IDGKR | VSSOP-8_3.0x3.0mm_P0.65mm | 3
57 | ✓ |  | IC24, IC29, IC33 | ADL5801 | QFN-24-1EP_4x4mm_P0.5mm_EP2.6x2.6mm | 3
58 | ✓ |  | IC25, IC30, IC34 | NCP702-1.8 | SOT-23-5 | 3
59 | ✓ |  | IC26, IC31, IC35 | MCP33131D-10-E/MS | VSSOP-10_3x3mm_P0.5mm | 3
60 | ✓ |  | T1, T2, T3 | B012-617DB-1-63-B331 | EASTEVER_BALUN | 3
61 | ✓ | ✓ | IC8, IC19 | AP2114H | SOT-223-3_TabPin2 | 2
62 | ✓ |  | IC9, IC20 | NCP702-3.3 | SOT-23-5 | 2
63 |  |  | IC10, IC21 | MAX2871 | QFN-32-1EP_5x5mm_P0.5mm_EP3.1x3.1mm | 2
64 | ✓ |  | IC11, IC12 | RFSW6042 | QFN40P180X180X55-13T76N | 2
65 | ✓ | ✓ | Q1, Q2 | SSM3J338R | SOT-23 | 2
66 | ✓ |  | IC1 | MIC2253 | DFN-12-1EP_3x3mm_P0.45mm_EP1.66x2.38mm | 1
67 | ✓ | ✓ | IC2 | LM3370 | DFN-16-1EP_4x5mm_P0.5mm_EP2.44x4.34mm | 1
68 | ✓ |  | IC7 | SI5351C | QFN-20-1EP_4x4mm_P0.5mm_EP2.7x2.7mm | 1
69 | ✓ |  | IC14 | RFSA3714 | QFN-24-1EP_4x4mm_P0.5mm_EP2.6x2.6mm | 1
70 | ✓ | ✓ | IC15 | TRF37A73 | DFN-8-1EP_2x2mm_P0.5mm_EP0.9x1.6mm | 1
71 | ✓ |  | IC37 | STM32G431CB | QFN-48-1EP_7x7mm_P0.5mm_EP5.6x5.6mm | 1
72 | ✓ | ✓ | JP1 | DNP | PinHeader_1x10_P2.54mm_Horizontal | 1
73 | ✓ | ✓ | JP2 | DNP | PinHeader_2x10_P2.54mm_Vertical | 1
74 | ✓ |  | LP1 | LP0603A-0947 | FILTRDFN160X84X70-4N | 1
75 | ✓ |  | LP2 | LP0603A-3500 | FILTRDFN160X84X70-4N | 1
76 | ✓ |  | LP3 | LP0603A-1880 | FILTRDFN160X84X70-4N | 1
77 |  |  | N1 | Top Cover | VNA_COVER_TOP | 1
78 | ✓ |  | J2, J3 | SMA | BU-1420701851 | 2
79 | ✓ | ✓ | J1 | PJ-014D | PJ-014D | 1
80 | ✓ | ✓ | J4 | USB_C_Receptacle_USB2.0_16P | USB_C_Receptacle_GCT_USB4105-xx-A_16P_TopMnt_Horizontal | 1

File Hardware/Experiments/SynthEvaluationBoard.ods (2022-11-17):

Qty | Value | Package | Parts | Description | Digikey
7 |  | 1X03 | JP1, JP2, JP7, JP8, JP10, JP11, JP12 | PIN HEADER | Available
1 |  | 1X05 | JP9 | PIN HEADER | Available
2 |  | 1X08 | JP3, JP4 | PIN HEADER | Available
1 |  | 2X03 | JP6 | PIN HEADER | Available
1 |  | 2X05 | JP5 | PIN HEADER | Available
1 |  | SJ | SJ1 | SMD solder JUMPER | DNP
2 | 0 | R0402 | R21, R22 | RESISTOR, European symbol | Kit
2 | 0R2 | R0402 | R1, R5 | RESISTOR, European symbol | 73L1R20JCT-ND‎ (https://www.digikey.de/product-detail/de/73L1R20J/73L1R20JCT-ND/1543538?itemSeq=365930882)
3 | 0R5 | R0402 | R2, R3, R4 | RESISTOR, European symbol | CSR0402FKR500CT-ND (https://www.digikey.de/product-detail/de/stackpole-electronics-inc/CSR0402FKR500/CSR0402FKR500CT-ND/5251270)
2 | 100 | R0402 | R32, R33 | RESISTOR, European symbol | Kit
4 | 100n | C0402 | C3, C4, C25, C26 | CAPACITOR, European symbol | Available
21 | 100n | C0402 | C36, C40, C41, C42, C43, C44, C45, C51, C52, C53, C54, C55, C56, C57, C58, C61, C64, C65, C66, C67, C68 | CAPACITOR, European symbol | Available
1 | 10k | R0402 | R26 | RESISTOR, European symbol | Kit
3 | 10n | C0402 | C16, C37, C38 | CAPACITOR, European symbol | Kit
8 | 10u | C0603 | C2, C6, C7, C9, C11, C12, C27, C35 | CAPACITOR, European symbol | JMK107ABJ106KA-T (https://www.digikey.de/product-detail/de/taiyo-yuden/JMK107ABJ106KA-T/587-6012-1-ND/8040675)
2 | 10u | C1206 | C78, C82 | CAPACITOR, European symbol | Available
2 | 12p | C0402 | C46, C49 | CAPACITOR, European symbol | CC0402JRNPO9BN120 (https://www.digikey.de/product-detail/de/yageo/CC0402JRNPO9BN120/311-1016-1-ND/302933)
13 | 1k | R0402 | R34, R35, R36, R37, R38, R39, R40, R41, R42, R43, R44, R45, R46 | RESISTOR, European symbol | Kit
1 | 1k5 | R0402 | R51 | RESISTOR, European symbol | Kit
6 | 1n | C0402 | C15, C21, C22, C23, C24, C39 | CAPACITOR, European symbol | Kit
7 | 1u | C0402 | C13, C17, C50, C62, C63, C195, C198 | CAPACITOR, European symbol | Kit
14 | 22 | R0402 | R9, R10, R11, R12, R13, R14, R15, R16, R17, R18, R19, R20, R49, R50 | RESISTOR, European symbol | Kit
4 | 220 | R0402 | R53, R54, R55, R56 | RESISTOR, European symbol | Kit
5 | 220n | C0402 | C1, C5, C8, C10, C14 | CAPACITOR, European symbol | Kit
1 | 470 | R0402 | R52 | RESISTOR, European symbol | Kit
2 | 47p | C0402 | C47, C48 | CAPACITOR, European symbol | 0402N470J250CT (https://www.digikey.de/product-detail/de/walsin-technology-corporation/0402N470J250CT/1292-1324-1-ND/9355328)
6 | 49R9 | R0402 | R25, R29, R30, R31, R23, R24 | RESISTOR, European symbol | PFR05S-49R9-FNH (https://www.digikey.de/product-detail/de/delta-electronics-cyntec/PFR05S-49R9-FNH/2037-PFR05S-49R9-FNHCT-ND/10124176)
2 | 4k7 | R0402 | R47, R48 | RESISTOR, European symbol | Kit
2 | 4p | C0402 | C59, C60 | CAPACITOR, European symbol | not required, Si5332 with embedded crystal used
1 | AD9913 | QFN50P500X500X80-33T310 | IC2 |  | AD9913BCPZ-ND (https://www.digikey.de/product-detail/de/analog-devices-inc/AD9913BCPZ/AD9913BCPZ-ND/1771153)
3 | AMPHENOL_901-10510-2 | AMPHENOL_901-10510-2 | J1, J2, J3 |  | ARF2496-ND‎ (https://www.digikey.de/product-detail/de/901-10510-2/ARF2496-ND/6051059?itemSeq=365928678)
1 | AP2114H | SOT230P700X180-4 | IC19 |  | not available, use from old board
1 | B012-617DB-1-63-B331 | EASTEVER_BALUN | T1 |  | Available
3 | BU-1420701851 | BU-1420701851 | J4, J5, J6 |  | 314-1703-ND‎ (https://www.digikey.de/product-detail/de/BU-1420701851/314-1703-ND/9950117?itemSeq=365928501)
3 | DNP | C0402 | C18, C19, C20 | CAPACITOR, European symbol | DNP
5 | DNP | R0402 | R6, R7, R8, R27, R28 | RESISTOR, European symbol | DNP
1 | ETC1-1T-2 | SM-22 | B1 |  | not available, skip for now
1 | FA-128 26MHz | FA-128 | Q1 | MHz RANGE CRYSTAL UNIT | not required, Si5332 with embedded crystal used
5 | FERRITE | R0402 | L1, L2, L9, L10, L11 |  | MFBM1V1005-101-R (https://www.digikey.de/product-detail/de/eaton-electronics-division/MFBM1V1005-101-R/283-MFBM1V1005-101-RCT-ND/13161392)
5 | Green | LED_SML0603 | LED1, LED2, LED3, LED4, LED5 | LED | Available
4 | LQW15AWR16J80D | L0402 | L3, L5, L6, L7 |  | LQW15AWR16J80D (https://www.digikey.de/product-detail/de/murata-electronics/LQW15AWR16J80D/490-LQW15AWR16J80DCT-ND/11690555)
2 | LQW15CAR27J00D | L0402 | L4, L8 |  | LQW15CAR27J00D (https://www.digikey.de/product-detail/de/murata-electronics/LQW15CAR27J00D/490-12212-1-ND/5415457)
1 | MINI-USB-SCHIELD-32005-301 | 32005-301 | X10 | MINI USB-B Conector | 102-4003-1-ND (https://www.digikey.de/product-detail/de/cui-devices/UJ2-MBH-1-SMT-TR/102-4003-1-ND/6187925)
2 | NCP702-1.8 | SOT95P240X110-5 | IC3, IC34 |  | NCP702SN18T1GOSCT-ND‎ (https://www.digikey.de/product-detail/de/NCP702SN18T1G/NCP702SN18T1GOSCT-ND/3152807?itemSeq=365927752)
6 | NFM18CC101R1C3D | NFM18PC | C28, C29, C30, C31, C32, C33 |  | 490-6961-1-ND‎ (https://www.digikey.de/product-detail/de/NFM18CC101R1C3D/490-6961-1-ND/3846158?itemSeq=365927677)
1 | NFM21PC475B1A3D | NFM21PC | C34 |  | 490-6983-1-ND‎ (https://www.digikey.de/product-detail/de/NFM21PC475B1A3D/490-6983-1-ND/3846180?itemSeq=365927621)
1 | SI5332A-GM1 | QFN50P500X500X100-33T345N | IC4 |  | 336-5566-ND (https://www.digikey.de/product-detail/de/silicon-labs/SI5332E-D-GM1/336-5566-ND/9553768) | Si5332E (with embedded crystal)
9 | SMA_CONNECTOR | J502-ND-142-0711-821/826 | X1, X2, X3, X4, X5, X6, X7, X8, X9 |  | Available
1 | STM32L462CE | QFN50P700X700X60-49T560N | IC5 |  | 497-16587-ND‎ (https://www.digikey.com/product-detail/en/STM32L443CCU6/497-16587-ND/6132758?itemSeq=365926876) | Pin-compatible alternative
1 | STW81200 | QFN50P600X600X100-37T410N | IC1 |  | 497-18618-ND‎ (https://www.digikey.de/product-detail/de/STW81200T/497-18618-ND/5268362?itemSeq=365927079)
1 | TE_2118718-2 | TE_2118718-2 | SH1 |  | A126153CT-ND‎ (https://www.digikey.de/product-detail/de/2118718-2/A126153CT-ND/7381913?itemSeq=365927154) | A126122-ND‎ (https://www.digikey.de/product-detail/de/2118717-2/A126122-ND/7381861?itemSeq=365927145)

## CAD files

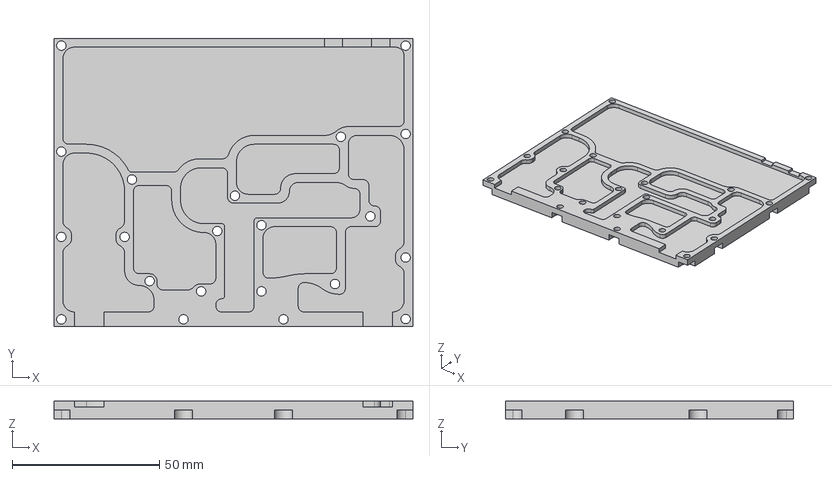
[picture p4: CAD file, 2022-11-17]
Hardware/BottomShield.step
122.0 x 98.0 x 6.00 mm

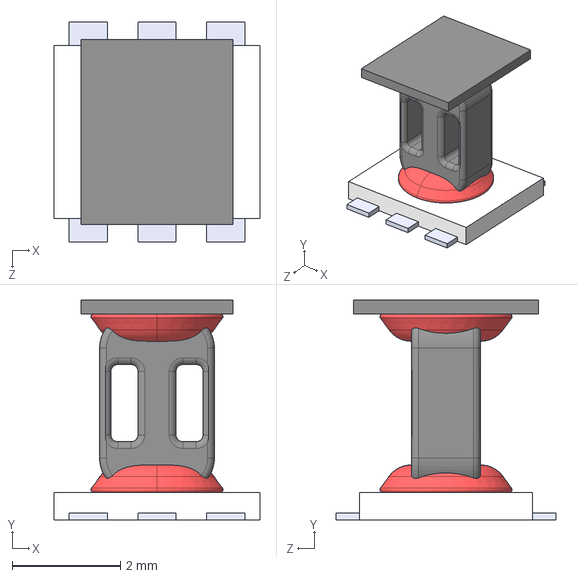
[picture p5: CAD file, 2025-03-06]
Hardware/Kicad/VNA.3dmodels/TCM1-63AX_.step
3.81 x 4.06 x 4.06 mm

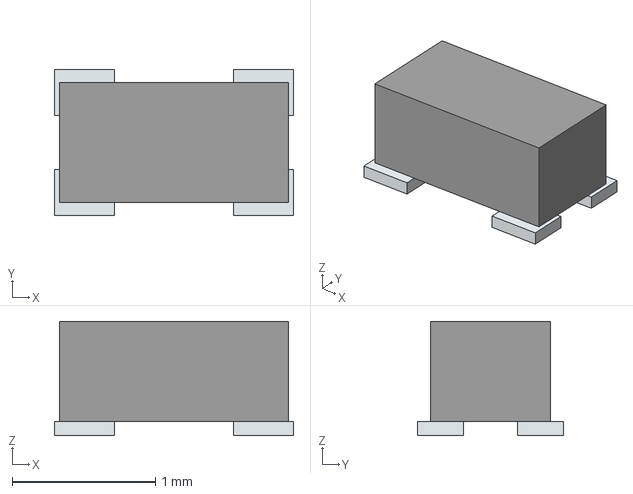
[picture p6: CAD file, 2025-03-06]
Hardware/Kicad/VNA.3dmodels/LP0603N3500ANTR.stp
1.67 x 1.02 x 0.8 mm
Pins

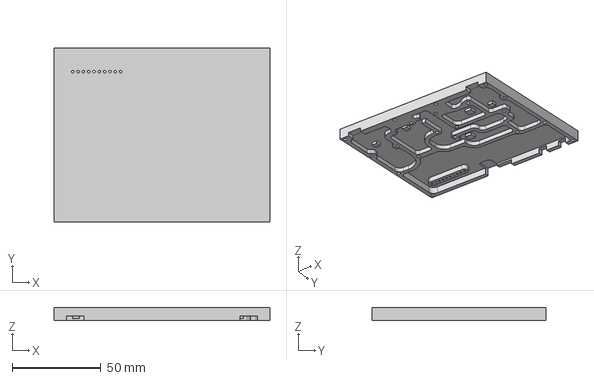
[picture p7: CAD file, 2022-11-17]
Hardware/TopShield.step
122.0 x 98.0 x 7.50 mm

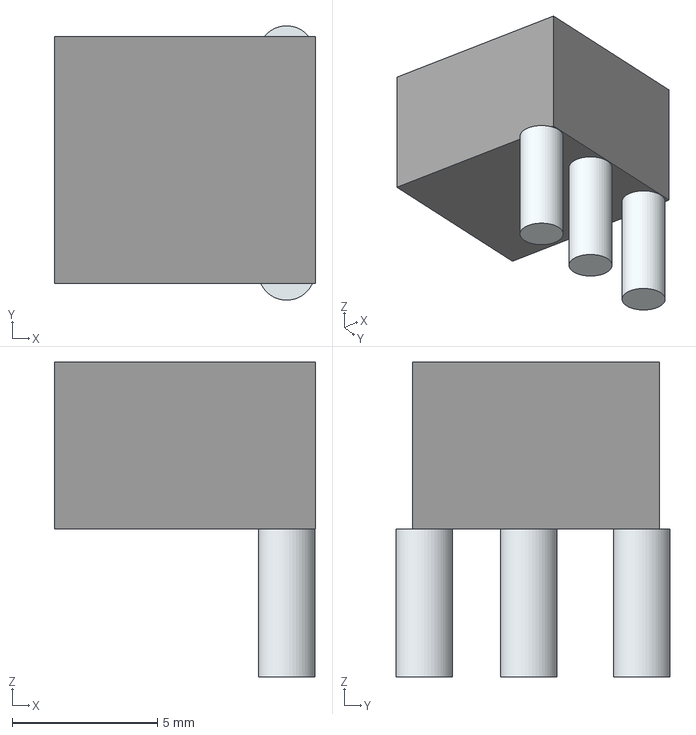
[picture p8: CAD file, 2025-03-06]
Hardware/Kicad/VNA.3dmodels/PJ-014D.stp
9.00 x 9.45 x 10.8 mm
Leads

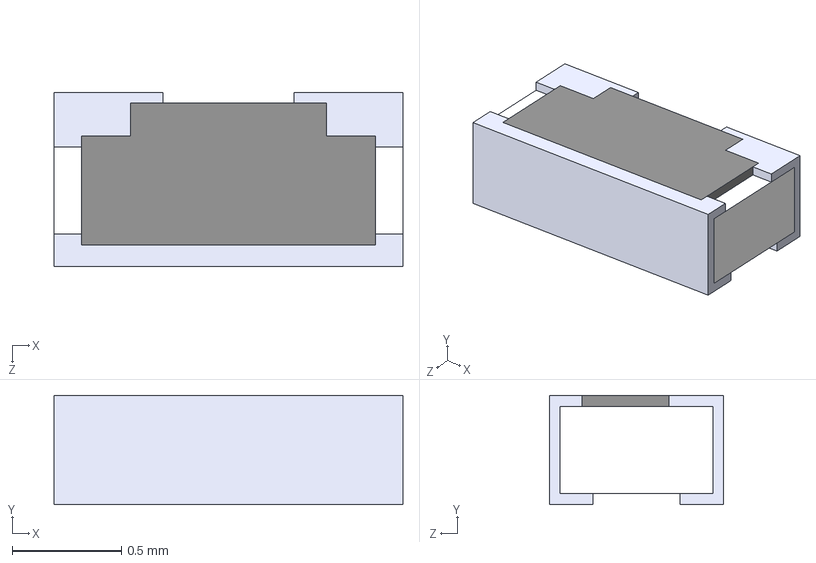
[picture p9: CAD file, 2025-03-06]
Hardware/Kicad/VNA.3dmodels/PAT0816-C-3DB-T5.STEP
1.60 x 0.5 x 0.8 mm

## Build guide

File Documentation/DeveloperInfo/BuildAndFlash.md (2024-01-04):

# Build instructions
This project consists of two software components: the PC application (written in C++/Qt) and the embedded VNA firmware (C/C++). The VNA firmware is further split into the MCU firmware and the FPGA configuration bitstream.
Creating all the different parts from the source code requires quite a few tools:
* For building the PC application:
  * [Qt Creator](https://www.qt.io/offline-installers) (at least with Qt 5.9)
  * [libusb-1.0](https://libusb.info/)
* For building the VNA firmware:
  * [STM32CubeIDE:](https://www.st.com/en/development-tools/stm32cubeide.html) Code generator and IDE for STM32 microcontrollers 
* For creating the FPGA bitstream:
  * [Xilinx ISE](https://www.xilinx.com/products/design-tools/ise-design-suite.html) with support for Spartan 6 FPGA
 
## Building the PC application:
* Install the required tools (Qt and libusb-1.0):
  ```
  sudo apt-get install libusb-1.0-0-dev qt6-tools-dev qt6-base-dev
  ```
* Build the application:
  * either:
  ```
  cd Software/PC_Application/LibreVNA-GUI
  qmake6
  make
  ```
  * or:
    * Open Software/PC_Application/LibreVNA-GUI/LibreVNA-GUI.pro with Qt Creator
    * Build the application with Qt Creator

## Building the MCU firmware:
* Importing the project (only has to be done once):
  * Open STM32CubeIDE with the workspace set to Software/
  * Import the project: File > Import... > General > Exisiting Projects into Workspace > Select root directory (should already be set to Software/) > Select the "VNA_embedded" project > Finish
* Build project: Project > Build Project
* Flashing/Debugging the MCU (only required once for a new hardware or when debugging):
  * Create build configuration if it doesn't exist alreay: Run > Run configurations > Create new "STM32 Cortex-M C/C++ Application" > In tab "Main" select the compiled .elf-file
  * Connect to the MCU with an ST-Link and the SWD pads on the PCB (requires removing the aluminium enclosure)
  * Flash/debug: Run > Run or Run > Debug

## Creating the FPGA bitstream:
* Open FPGA/VNA/VNA.xise in Xilinx ISE
* In the Design tab, select the implementation view and then "top - Behavioral"
* In the Processes tab, doubleclick "Generate Programming File". This will take a couple of minutes.

## Assembling the combined VNA firmware:
Only on a new hardware with an empty microcontroller it is required to flash the MCU firmware once. After that updates are possible through the USB port. Updating the firmware requires a combined fimrware image that contains both the MCU firmware as well as the FPGA bitstream and some header data.
* Make sure you compiled the MCU firmware: there should be a binary file "VNA_embedded.bin" in Software/VNA_embedded/[Debug/Release]
* Make sure you have the FPGA bitstream: there should be a file "top.bin" in FPGA/VNA
* Execute the script "AssembleFirmware.py" in the root directory. This creates a combined firmware file "combined.vnafw"

## Getting a new board running:
1. Flash the compiled MCU firmware by directly connecting to the SWD pads on the board with an ST-Link and using OpenOCD/ST-Link utility/...
2. The "Booting" LED should indicate an error code 2 (invalid FLASH content). This does not refer to MCU flash but rather the onboard flash chip which is empty at this point.
3. Perform a firmware update using the PC application and the combined firmware:
    1. Open the compiled PC application
    2. Connect to the device if not already connected: Device > Update Device List and then Device > Connect to > Select your serialnumber
    3. Perform firmware update: Device > Firmware Update, select the "combined.vnafw" and click Start
4. The board should reboot and not report an error condition anymore (only "Ready" and "Power" LED on)

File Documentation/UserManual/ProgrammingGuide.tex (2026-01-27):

\documentclass[a4paper,11pt]{article}

\usepackage[utf8]{inputenc}
\usepackage[T1]{fontenc} % LY1 also works
\usepackage[margin=1in]{geometry}

%% Font settings suggested by fbb documentation.
\usepackage{textcomp} % to get the right copyright, etc.
\usepackage[lining,tabular]{fbb} % so math uses tabular lining figures
\usepackage[scaled=.95,type1]{cabin} % sans serif in style of Gill Sans
\usepackage[varqu,varl]{zi4}% inconsolata typewriter
\useosf % change normal text to use proportional oldstyle figures
%\usetosf would provide tabular oldstyle figures in text

\usepackage{microtype}
\usepackage{siunitx}
\DeclareSIUnit{\belmilliwatt}{Bm}
\DeclareSIUnit{\dBm}{\deci\belmilliwatt}
\sisetup{range-phrase=--, range-units=single, binary-units = true}
\usepackage{graphicx}
\usepackage{tikz}
\usepackage{svg}
%\usepackage{hyperref}
\usetikzlibrary{arrows, shadows}
\tikzset{%
  cascaded/.style = {%
    general shadow = {%
      shadow scale = 1,
      shadow xshift = -1ex,
      shadow yshift = 1ex,
      draw,
      thick,
      fill = white},
    general shadow = {%
      shadow scale = 1,
      shadow xshift = -.5ex,
      shadow yshift = .5ex,
      draw,
      thick,
      fill = white},
    fill = white, 
    draw,
    thick,
    minimum width = 1.5cm,
    minimum height = 2cm}}
    
\usepackage{enumitem}
\usepackage{longtable}
\setitemize{noitemsep,topsep=0pt,parsep=0pt,partopsep=0pt}
\setlist{leftmargin=*}
\usepackage{listings}
\definecolor{darkgreen}{RGB}{0,140,0}
\lstset{
	basicstyle=\ttfamily,
	frame=single,
	breaklines=true,
	morecomment=[l][\color{darkgreen}]{\#},
}
\lstnewenvironment{example}{\lstset{
    ,frame=single
    ,xleftmargin=2em
    ,xrightmargin=2em
   % ,backgroundcolor=\color{lightgray}
    ,title=Example
}}{}
\usepackage[os=win]{menukeys}
\renewmenumacro{\keys}[+]{shadowedroundedkeys}

\usepackage{booktabs,caption}
\usepackage[flushleft]{threeparttable}
\newcolumntype{L}[1]{>{\raggedright\let\newline\\\arraybackslash\hspace{0pt}}m{#1}}
\newcolumntype{C}[1]{>{\centering\let\newline\\\arraybackslash\hspace{0pt}}m{#1}}
\newcolumntype{R}[1]{>{\raggedleft\let\newline\\\arraybackslash\hspace{0pt}}m{#1}}
\usepackage{tabularx} 

\usepackage{stackengine}
\usepackage{scalerel}
\usepackage{xcolor,mdframed}
\newcommand\danger[1][5ex]{%
  \renewcommand\stacktype{L}%
  \scaleto{\stackon[1.3pt]{\color{red}$\triangle$}{\tiny !}}{#1}%
}

\newenvironment{important}[1][]{%
   \begin{mdframed}[%
      backgroundcolor={red!15}, hidealllines=true,
      skipabove=0.7\baselineskip, skipbelow=0.7\baselineskip,
      splitbottomskip=2pt, splittopskip=4pt, #1]%
   \makebox[0pt]{% ignore the withd of !
      \smash{% ignor the height of !
         %\fontsize{32pt}{32pt}\selectfont% make the ! bigger
         \hspace*{-45pt}% move ! to the left
         \raisebox{-5pt}{% move ! up a little
            {\danger}% type the bold red !
         }%
      }%
   }%
}{\end{mdframed}}

\newcommand\info[1][5ex]{%
  \renewcommand\stacktype{L}%
  \scaleto{\stackon[1.2pt]{\color{blue}$\bigcirc$}{\raisebox{-1.5pt}{\small i}}}{#1}%
}

\newenvironment{information}[1][]{%
   \begin{mdframed}[%
      backgroundcolor={blue!15}, hidealllines=true,
      skipabove=0.7\baselineskip, skipbelow=0.7\baselineskip,
      splitbottomskip=2pt, splittopskip=4pt, #1]%
   \makebox[0pt]{% ignore the withd of !
      \smash{% ignor the height of !
         %\fontsize{32pt}{32pt}\selectfont% make the ! bigger
         \hspace*{-45pt}% move ! to the left
         \raisebox{-5pt}{% move ! up a little
            {\info}% type the bold red !
         }%
      }%
   }%
}{\end{mdframed}}

\usepackage{makecell}
\usepackage{hyperref}
\usepackage{xifthen}
\newcommand{\vna}{LibreVNA}
\newcommand{\gui}{\vna{}-GUI}
\newcommand{\subsubsubsection}[1]{\paragraph{#1}\mbox{}\\\\}

\newcommand{\screenshot}[2]{\begin{center}

\end{center}}

\newcommand{\event}[3]{
\noindent\textbf{Event:}
\begin{longtable}{p{.15\textwidth} | p{.80\textwidth} } 
\hline
\textbf{Effect:} & #1 \\ \hline
\textbf{Syntax:} & #2 \\ \hline 
\textbf{Parameters:} & \makecell[Xl]{#3} \\ \hline
\end{longtable}
}
\newcommand{\query}[4]{
\noindent\textbf{Query:}
\begin{longtable}{p{.15\textwidth} | p{.80\textwidth} } 
\hline
\textbf{Effect:} & #1 \\ \hline
\textbf{Syntax:} & #2 \\ \hline 
\textbf{Parameters:} & \makecell[tl]{#3} \\ \hline
\textbf{Return value:} & \makecell[tl]{#4} \\ \hline
\end{longtable}
}

\title{\vna{} SCPI Programming Guide}
\begin{document}
\maketitle

\setcounter{tocdepth}{4}
\setcounter{secnumdepth}{4}
\tableofcontents

\clearpage

\section{Introduction}
The \gui{} contains a TCP server that can be used to control the \vna{} with SCPI commands.
\section{SCPI Server Configuration}
The server is configurable in the preferences: \menu[,]{Window,Preferences,General}
\screenshot{0.3}{serverconfig.png}
If enabled, it will accept any TCP connection at the configured port. Once the connection is established, it can be used to send SCPI commands and receive replies. Only one connection at a time is possible, if a second connection is created, the first one will be closed by the \gui{}. Alternatively, a port can be manually configured by setting the ``port'' argument:
\begin{lstlisting}
./LibreVNA-GUI --port 1234
\end{lstlisting}
This enables the SCPI server at the specified port, regardless of what is configured in the preferences (useful for starting multiple instances at different ports at the same time). If no graphical user interface is required, the \gui{} can be hidden:
\begin{lstlisting}
./LibreVNA-GUI --port 1234 --no-gui
\end{lstlisting}
\section{General Syntax}
The syntax follows the usual SCPI rules:
\begin{itemize}
\item All commands are case insensitive (implicitly converted to uppercase before evaluated)
\item The command tree is organized in branches, separated by a colon:
\begin{lstlisting}
VNA:TRACE:LIST?
\end{lstlisting}
\item Multiple commands can be concatenated in one line using a semicolon:
\begin{lstlisting}
DEVice:CONNECT;:DEVice:INFo:FWRevision?
\end{lstlisting}
\item If a subsequent command starts with a colon it is evaluated from the root branch, otherwise the last used branch is assumed:
\begin{lstlisting}
VNA:FREQuency:START 1000000;STOP 2000000 #No colon, VNA:FREQuency branch was used before
\end{lstlisting}
\item Branches and commands can be abbreviated by using only the uppercase part of their name, the following commands are identical:
\begin{lstlisting}
DEVice:INFo:LIMits:MINFrequency?
DEV:INF:LIM:MINF?
\end{lstlisting}
\item Every query generates a response, terminated with a newline character (exceptions exist for a few queries which return more than one line)
\item Some commands require additional arguments that have to be passed after the command (separated by spaces):
\begin{lstlisting}
DEV:REF:OUT 10
\end{lstlisting}
\item Two types of commands are available:
\begin{itemize}
\item \textbf{Events} change a setting or trigger an action. They have no response
\item \textbf{Queries} request information. They end with a question mark.
\end{itemize}
Some commands are both events and queries, depending on whether the question mark is present:
\begin{lstlisting}
VNA:FREQ:SPAN 50000000 # Set the span
VNA:FREQ:SPAN? # Read the current span
\end{lstlisting}
\end{itemize}
\section{Commands}
\subsection{General Commands}
\subsubsection{*IDN}
\query{Returns the identifications string}{*IDN?}{None}{LibreVNA,LibreVNA-GUI,<serial>,<software version>}
\begin{itemize}
\item The serial number is the serial number from the connected LibreVNA. If none is connected, it will be set to ``Not connected''
\item The software version is the version of the \gui{}, not the firmware version of the connected \vna{}
\end{itemize}
\subsubsection{*RST}
\event{Resets the GUI (and any connected device) to the default state}{*RST}{None}
\subsubsection{*CLS}
\event{Clears the event status register}{*CLI}{None}
\subsubsection{*ESE}
\event{Configures the event status enable register}{*ESE}{<enabled\_bits\_decimal>}
\query{Returns the event status enable register}{*ESE?}{None}{<enabled\_bits\_decimal>}
\subsubsection{*ESR}
\query{Returns the event status register}{*ESR?}{None}{<set\_bits\_decimal>}
The bits are used according to IEEE 488:
\begin{longtable}{p{.1\textwidth} | p{.1\textwidth} | p{.4\textwidth} }
\textbf{Bitvalue} & \textbf{Name} & \textbf{Meaning}\\
\hline
1 & OPC & Operation complete\\
2 & RQC & Request control (not used)\\
4 & QYE & Query error (not used)\\
8 & DDE & Device dependent error (not used)\\
16 & EXE & Execution error (not used)\\
32 & CME & Command error\\
64 & URQ & User request (not used)\\
128 & PON & Power on (not used)\\
\end{longtable}
\subsubsection{*OPC}
\event{Sets the OPC bit in the event status register after all operations are complete}{*OPC}{None}
\query{Returns a 1 after every active operation has completed}{*OPC?}{None}{1}
\subsubsection{*WAI}
\event{Blocks further command parsing until all active operations are complete}{*WAI}{None}
\subsubsection{*LST}
\query{Lists all available commands}{*LST?}{None}{List of commands, separated by newline}
\subsection{Device Commands}
This section contains general device commands, available regardless of the current mode.
\subsubsection{DEVice:DISConnect}
\event{Disconnects from the device}{DEVice:DISConnect}{None}

\subsubsection{DEVice:CONNect}
\event{Connects to a device. If no serialnumber is specified, the connection is made with the first device found}{DEVice:CONNect [<serialnumber>]}{<serialnumber> Serialnumber of the device that should be connected}
\begin{example}
:DEV:CONN 206039903350
\end{example}
\query{Queries the serial number of the connected device}{DEVice:CONNect?}{None}{<serialnumber> or ``Not connected''}
\begin{example}
:DEV:CONN?
206039903350
\end{example}

\subsubsection{DEVice:LIST}
\query{Lists all available devices by their serial numbers}{DEVice:LIST?}{None}{List of serialnumbers}
\begin{example}
:DEV:LIST?
206039903350,208939A23350
\end{example}

\subsubsection{DEVice:PREFerences}
This command provides read/write access to the preferences. The recommended way is usually to change the preferences manually in the GUI. But if for some reason that is not an option, this is also possible through the SCPI server. There is no complete documentation for all available preferences, refer to the source code.

\event{Set a preferences entry}{DEVice:PREFerences <name> <value>}{<name> Name of the preferences entry\\ <value> New value for the preferences entry}
\begin{example}
:DEV:PREF Startup.ConnectToFirstDevice false
\end{example}
Most settings take effect immediately but some (such as changing the port for the SCPI server) are only applied when the preferences are saved. Also see command~\ref{DEV:APPLYPREF}.

\query{Returns a preferences entry}{DEVice:PREFerences? <name>}{<name> Name of the preferences entry}{Current value of the preferences entry}

\subsubsection{DEVice:APPLYPREFerences}
\label{DEV:APPLYPREF}
\event{Permanently stores the preferences after a setting has been changed}{DEVice:APPLYPREFerences}{None}

\subsubsection{DEVice:MODE}
\event{Switches the device to the specified mode}{DEVice:MODE <mode>}{<mode>:\\ \hspace{1cm} VNA: set to vector analyzer\\ \hspace{1cm} GEN: set to signal generator\\ \hspace{1cm} SA: set to spectrum analyzer}
\begin{example}
:DEV:MODE VNA
\end{example}
\query{Queries the currently active mode}{DEVice:MODE?}{None}{<mode>:\\ \hspace{1cm} VNA: set to vector analyzer\\ \hspace{1cm} GEN: set to signal generator\\ \hspace{1cm} SA: set to spectrum analyzer}
\begin{example}
:DEV:MODE?
VNA
\end{example}

\subsubsection{DEVice:SETUP:SAVE}
\event{Saves the GUI setup to a file}{DEVice:SETUP:SAVE}{<filename>}
Important points when saving/loading setup files through SCPI commands:
\begin{itemize}
\item Filenames must be either absolute or relative to the location of the GUI application.
\item If the LibreVNA-GUI (and thus also the SCPI server) is running on a different machine than the SCPI client, the setup files will be saved/loaded from the machine that runs the GUI.
\item If no (or a wrong) file ending is specified, ``.setup'' is automatically added to the filename.
\end{itemize}

\subsubsection{DEVice:SETUP:LOAD}
\query{Loads a setup file}{DEVice:SETUP:LOAD?}{<filename>}{TRUE or FALSE}
\begin{itemize}
\item Filenames must be either absolute or relative to the location of the GUI application.
\item The filename must include the file ending ``.setup''.
\end{itemize}

\subsubsection{DEVice:REFerence:OUT}
\event{Sets the reference output frequency}{DEVice:REFerence:OUT <freq>}{<freq> in MHz, either 0 (disabled), 10 or 100}
\query{Queries the reference output frequency}{DEVice:REFerence:OUT?}{None}{Output frequency in MHz}

\subsubsection{DEVice:REFerence:IN}
\event{Set the reference input mode}{DEVice:REFerence:IN <mode>}{<mode>:\\ \hspace{1cm} INT: use internal reference\\ \hspace{1cm} EXT: use external reference\\ \hspace{1cm} AUTO: automatic reference switching}
\query{Queries the reference source}{DEVice:REFerence:IN?}{None}{INT or EXT}

\subsubsection{DEVice:STAtus:UNLOcked}
\query{Queries the PLL lock error flag}{DEVice:STAtus:UNLOcked?}{None}{TRUE or FALSE}

\subsubsection{DEVice:STAtus:ADCOVERload}
\query{Queries the ADC overload error flag}{DEVice:STAtus:ADCOVERload?}{None}{TRUE or FALSE}

\subsubsection{DEVice:STAtus:UNLEVel}
\query{Queries the output level error flag}{DEVice:STAtus:UNLEVel?}{None}{TRUE or FALSE}

\subsubsection{DEVice:INFo:FWREVision}
\query{Returns the firmware revision of the connected device}{DEVice:INFo:FWREVision?}{None}{<mayor>.<minor>.<patch>}
\begin{example}
:DEV:INF:FWREV?
1.0.0
\end{example}
\subsubsection{DEVice:INFo:HWREVision}
\query{Returns the hardware revision of the connected device}{DEVice:INFo:HWREVision?}{None}{<revision>, single char}
\begin{example}
:DEV:INF:HWREV?
B
\end{example}

\subsubsection{DEVice:INFo:LIMits:MINFrequency}
\query{Queries the lowest frequency the device can measure}{DEVice:INFo:LIMits:MINFrequency?}{None}{lowest frequency in Hz}

\subsubsection{DEVice:INFo:LIMits:MAXFrequency}
\query{Queries the highest frequency the device can measure}{DEVice:INFo:LIMits:MAXFrequency?}{None}{highest frequency in Hz}

\subsubsection{DEVice:INFo:LIMits:MINIFBW}
\query{Queries the lowest IF bandwidth setting}{DEVice:INFo:LIMits:MINIFBW?}{None}{lowest possible IF bandwidth in Hz}

\subsubsection{DEVice:INFo:LIMits:MAXIFBW}
\query{Queries the highest IF bandwidth setting}{DEVice:INFo:LIMits:MAXIFBW?}{None}{highest possible IF bandwidth in Hz}

\subsubsection{DEVice:INFo:LIMits:MAXPoints}
\query{Queries the maximum number of points per sweep}{DEVice:INFo:LIMits:MAXPoints?}{None}{maximum number of points}

\subsubsection{DEVice:INFo:LIMits:MINPOWer}
\query{Queries the minimum output power}{DEVice:INFo:LIMits:MINPOWer?}{None}{minimum output power in dBm}

\subsubsection{DEVice:INFo:LIMits:MAXPOWer}
\query{Queries the maximum output power}{DEVice:INFo:LIMits:MAXPOWer?}{None}{maximum output power in dBm}

\subsubsection{DEVice:INFo:LIMits:MINRBW}
\query{Queries the lowest resolution bandwidth setting}{DEVice:INFo:LIMits:MINRBW?}{None}{lowest possible resolution bandwidth in Hz}

\subsubsection{DEVice:INFo:LIMits:MAXRBW}
\query{Queries the highest resolution bandwidth setting}{DEVice:INFo:LIMits:MAXRBW?}{None}{highest possible resolution bandwidth in Hz}

\subsubsection{DEVice:INFo:LIMits:MAXHARMonicfrequency}
\query{Queries the (theoretical) maximum frequency when using harmonic mixing in VNA mode}{DEVice:INFo:LIMits:MAXHARMonicfrequency?}{None}{maximum frequency in Hz}

\subsection{VNA Commands}
These commands change or query VNA settings. Although most of them are available regardless of the current device mode, they usually only have an effect once the VNA mode is active (e.g. it is possible to change the span while in signal generator mode but it does not effect the \vna{} until the mode is switched to VNA). Certain commands (like taking a calibration measurement) are only available in VNA mode and will return an error if another mode is active.

\subsubsection{VNA:SWEEP}
\event{Sets the type of the sweep}{VNA:SWEEP}{<type>, either FREQUENCY or POWER}
\query{Queries the currently selected type}{VNA:SWEEP?}{None}{<type>, either FREQUENCY or POWER}

\subsubsection{VNA:FREQuency:SPAN}
\event{Sets the span of the sweep}{VNA:FREQuency:SPAN}{<span>, in Hz}
\query{Queries the currently selected span}{VNA:FREQuency:SPAN?}{None}{span in Hz}

\subsubsection{VNA:FREQuency:START}
\event{Sets the start frequency of the sweep}{VNA:FREQuency:START}{<start frequency>, in Hz}
\query{Queries the currently selected start frequency}{VNA:FREQuency:START?}{None}{start frequency in Hz}

\subsubsection{VNA:FREQuency:CENTer}
\event{Sets the center frequency of the sweep}{VNA:FREQuency:CENTer}{<center frequency>, in Hz}
\query{Queries the currently selected center frequency}{VNA:FREQuency:CENTer?}{None}{center frequency in Hz}

\subsubsection{VNA:FREQuency:STOP}
\event{Sets the stop frequency of the sweep}{VNA:FREQuency:STOP}{<stop frequency>, in Hz}
\query{Queries the currently selected stop frequency}{VNA:FREQuency:STOP?}{None}{stop frequency in Hz}

\subsubsection{VNA:FREQuency:FULL}
\event{Sets the device to the maximum span possible}{VNA:FREQuency:FULL}{None}

\subsubsection{VNA:FREQuency:ZERO}
\event{Sets the device to zero span mode}{VNA:FREQuency:ZERO}{None}

\subsubsection{VNA:POWer:START}
\event{Sets the start power of the power sweep}{VNA:POWer:START}{<start power>, in dBm}
\query{Queries the currently selected start power}{VNA:POWer:START?}{None}{start power in dBm}

\subsubsection{VNA:POWer:STOP}
\event{Sets the stop power of the power sweep}{VNA:POWer:STOP}{<stop power>, in dBm}
\query{Queries the currently selected stop power}{VNA:POWer:STOP?}{None}{stop power in dBm}

\subsubsection{VNA:SWEEPTYPE}
\event{Selects between linear and logarithmic sweeps}{VNA:SWEEPTYPE}{<type>, either ``LIN'' or ``LOG''}
\query{Queries the currently selected sweep type}{VNA:SWEEPTYPE?}{None}{``LIN'' or ``LOG''}

\subsubsection{VNA:ACQuisition:RUN}
\event{Puts the VNA into run mode (sweep active)}{VNA:ACQuisition:RUN}{None}
\query{Queries whether the VNA is in run mode}{VNA:ACQuisition:RUN?}{None}{TRUE or FALSE}

\subsubsection{VNA:ACQuisition:STOP}
\event{Puts the VNA into stop mode (sweep inactive)}{VNA:ACQuisition:STOP}{None}

\subsubsection{VNA:ACQuisition:IFBW}
\event{Sets the IF bandwidth}{VNA:ACQuisition:IFBW}{<IF bandwidth>, in Hz}
\query{Queries the currently selected IF bandwidth}{VNA:ACQuisition:IFBW?}{None}{IF bandwidth in Hz}

\subsubsection{VNA:ACQuisition:DWELLtime}
\event{Sets the dwell time}{VNA:ACQuisition:DWELLtime}{<dwell time>, in seconds}
\query{Queries the currently selected dwell time}{VNA:ACQuisition:DWELLtime?}{None}{dwell time in seconds}

\subsubsection{VNA:ACQuisition:POINTS}
\event{Sets the number of points per sweep}{VNA:ACQuisition:POINTS}{<points>}
\query{Queries the currently selected number of points}{VNA:ACQuisition:POINTS?}{None}{points}

\subsubsection{VNA:ACQuisition:AVG}
\event{Sets the number of sweeps over which a moving average is calculated}{VNA:ACQuisition:AVG}{<averaging sweeps>}
\query{Queries the currently configured number of sweeps}{VNA:ACQuisition:AVG?}{None}{<averaging sweeps>}

\subsubsection{VNA:ACQuisition:AVGLEVel}
\query{Queries the number of sweeps that have been acquired by the average function.}{VNA:ACQuisition:AVGLEVel?}{None}{<acquired sweeps>}
<acquired sweeps> resets to zero whenever a setting is changed. It is incremented at the end of each sweep, but will not go above the number of configured sweeps for the averaging.

Example (assuming <averaging sweep> = 3):
\begin{longtable}{p{.2\textwidth} | p{.2\textwidth} }
\textbf{\# of active sweep} & \textbf{<acquired sweeps>}\\
\hline
1 & 0\\
2 & 1\\
3 & 2\\
4 & 3\\
5 & 3\\
\end{longtable}

\subsubsection{VNA:ACQuisition:FINished}
\query{Queries whether the average filter has reached a steady state (that is <acquired sweeps> = <averaging sweeps>)}{VNA:ACQuisition:FINished?}{None}{TRUE or FALSE}

\subsubsection{VNA:ACQuisition:LIMit}
\query{Queries the status of limits that maybe set up on any graph}{VNA:ACQuisition:LIMit?}{None}{PASS or FAIL}

\subsubsection{VNA:ACQuisition:SINGLE}
\event{Configures the VNA for single or continuous sweep}{VNA:ACQuisition:SINGLE}{TRUE or FALSE}
\query{Queries whether the VNA is set up for single sweep}{VNA:ACQuisition:SINGLE?}{None}{TRUE or FALSE}

If single sweep is enabled, the acquisition is stopped when the required number of averages have been reached. There are two ways to trigger a new sweep:
\begin{itemize}
\item Change any sweep setting (e.g. center frequency)
\item Issue the command again (i.e. VNA:ACQ:SINGLE TRUE always triggers a new sweep)
\end{itemize}

\subsubsection{VNA:ACQuisition:FREQuency}
\query{Returns the current frequency of the sweep}{VNA:ACQuisition:FREQuency?}{None}{<Frequency in Hz>}

This command only returns valid data when a sweep is running and the the sweep is a frequency sweep.

\subsubsection{VNA:ACQuisition:POWer}
\query{Returns the current power of the sweep}{VNA:ACQuisition:POWer?}{None}{<Power in dBm>}

This command only returns valid data when a sweep is running and the the sweep is a power sweep.

\subsubsection{VNA:ACQuisition:TIME}
\query{Returns the current time of the sweep}{VNA:ACQuisition:TIME?}{None}{<Time in seconds>}

This command only returns valid data when a sweep is running and the the sweep is a zero-span sweep.

\subsubsection{VNA:STIMulus:LVL}
\event{Sets the output power of the stimulus signal when sweep type is frequency}{VNA:STIMulus:LVL}{<power>, in dBm}
\query{Queries the currently selected output power}{VNA:STIMulus:LVL?}{None}{power in dBm}

\subsubsection{VNA:STIMulus:FREQuency}
\event{Sets the frequency of the stimulus signal when sweep type is power}{VNA:STIMulus:FREQuency}{<freq>, in Hz}
\query{Queries the currently selected frequency}{VNA:STIMulus:FREQuency?}{None}{frequency in Hz}

\subsubsection{VNA:TRACe:LIST}
\query{Lists the names of all available traces}{VNA:TRACe:LIST?}{None}{comma-separated list of trace name}
\begin{example}
VNA:TRAC:LIST?
S11,S12,S21,S22
\end{example}

\subsubsection{VNA:TRACe:DATA}
\query{Returns the data of a trace}{VNA:TRACe:DATA?}{<trace>, either by name or by index}{comma-separated list of tuples [x, real(y), imag(y]}
Depending on the sweep and possible confiigured math operations, x may be either frequency, power or time.
\begin{example}
:VNA:TRAC:DATA? S11
[1e+6,0.400172,0.0377869],
[6.67556e+8,-0.0922281,-0.00990373],
[1.33411e+9,-0.0341439,-0.0331184],
[2.00067e+9,0.00750893,0.0490847],
[2.66722e+9,0.0472666,-0.175552],
[3.33378e+9,-0.106545,-0.00952825],
[4.00033e+9,-0.102039,0.0890605],
[4.66689e+9,0.0464292,0.118183],
[5.33344e+9,0.13223,-0.00780554],
[6e+9,-0.0314859,-0.246024]
\end{example}
\vspace{-0.3cm}
\begin{center}
\footnotesize{Note: actual response will not include newlines between data points, only at the end}
\end{center}

\subsubsection{VNA:TRACe:AT}
\query{Returns the data at a specific frequency (possibly interpolated)}{VNA:TRACe:AT?}{<trace>, either by name or by index\\<frequency>, in Hz}{real,imag (or ``NaN,NaN'' if specified frequeny is invalid)}
\begin{example}
:VNA:TRAC:AT? S11 1200000000
-0.0458452,-0.028729
\end{example}

\subsubsection{VNA:TRACe:TOUCHSTONE}
\query{Returns the content of multiple trace according to the touchstone format}{VNA:TRACe:TOUCHSTONE?}{<trace1>,<trace2>,<trace3>,...}{Touchstone file content in ASCII}
Some additional constraints apply:
\begin{itemize}
\item The number of specified traces must be a square number. The number of ports in the touchstone file is inferred from that.
\item Only frequency domain traces are allowed.
\item All traces must have the same number of points and the same start/stop frequency.
\item The order in which the traces are specified matters and depending on its index and each trace must be a reflection or transmission measurement:
\begin{itemize}
\item Assuming that $n$ is the number of ports of the desired touchstone file, the $n*n$ number of traces must be specified in this order:
$$ S_{11}...S_{1n},S_{21}...S_{2n},...,S_{n1}...S_{nn} $$
\item For every trace $S_{ij}$, the trace must contain a reflection measurement if $i=j$ and a transmission measurement if $i\neq j$.
\end{itemize}
\item Traces can be specified either by name or by index.
\item A deviation from any of these points (invalid number of traces, non-existing trace, wrong order, ...) will result in an error being returned.
\end{itemize}
\begin{example}
:VNA:TRACE:TOUCHSTONE? S11 S12 S21 S22
# GHZ S RI R 50
1.000000000000 1.000497817993 0.010679213330 0.000013886895 -0.000054684886 -0.000023392624 -0.000021111371 0.401717424393 0.702864229679
1.002000000000 1.000323534012 0.010577851906 -0.000011075452 -0.000013504875 0.000000477609 -0.000007789199 0.413144201040 0.696514129639
...
\end{example}

\subsubsection{VNA:TRACe:MAXFrequency}
\query{Returns the highest frequency contained in the trace}{VNA:TRACe:MAXFrequency?}{<trace>, either by name or by index}{maximum frequency in Hz}

\subsubsection{VNA:TRACe:MINFrequency}
\query{Returns the lowest frequency contained in the trace}{VNA:TRACe:MINFrequency?}{<trace>, either by name or by index}{maximum frequency in Hz}

\subsubsection{VNA:TRACe:MAXAmplitude}
\query{Returns the datapoint with the highest amplitude in the trace}{VNA:TRACe:MAXAmplitude?}{<trace>, either by name or by index}{<frequency>,<real>,<imag> of the highest amplitude point}
\begin{example}
:VNA:TRAC:MAXA? S21
5.66406e+9,-6.21766e-5,-0.000795846
\end{example}

\subsubsection{VNA:TRACe:MINAmplitude}
\query{Returns the datapoint with the lowest amplitude in the trace}{VNA:TRACe:MINAmplitude?}{<trace>, either by name or by index}{<frequency>,<real>,<imag> of the lowest amplitude point}

\subsubsection{VNA:TRACe:NEW}
\event{Creates a new trace}{VNA:TRACe:NEW}{<trace name>}

\subsubsection{VNA:TRACe:DELete}
\event{Deletes a trace}{VNA:TRACe:DELete}{<trace>, either by name or by index}

\subsubsection{VNA:TRACe:RENAME}
\event{Changes the name of a trace}{VNA:TRACe:RENAME}{<trace>, either by name or by index\\<new name>}

\subsubsection{VNA:TRACe:PAUSE}
\event{Pauses (freezes) a trace}{VNA:TRACe:PAUSE}{<trace>, either by name or by index}

\subsubsection{VNA:TRACe:RESUME}
\event{Resumes (unfreezes) a trace}{VNA:TRACe:RESUME}{<trace>, either by name or by index}

\subsubsection{VNA:TRACe:PAUSED}
\query{Queries whether a trace is paused}{VNA:TRACe:PAUSED?}{<trace>, either by name or by index}{TRUE or FALSE}

\subsubsection{VNA:TRACe:DEEMBedding:ACTive}
\event{Enables/disables de-embedding on a trace}{VNA:TRACe:DEEMBedding:ACTive}{<trace>, either by name or by index\\<enable>, either TRUE or FALSE}

If no de-embedding is configured for the selected trace, enabling the de-embedding will fail.

\query{Queries whether de-embedding is active for the selected trace}{VNA:TRACe:DEEMBedding:ACTive?}{<trace>, either by name or by index}{TRUE or FALSE}

\subsubsection{VNA:TRACe:DEEMBedding:AVAILable}
\query{Queries whether de-embedding is available for the selected trace}{VNA:TRACe:DEEMBedding:AVAILable?}{<trace>, either by name or by index}{TRUE or FALSE}

\subsubsection{VNA:TRACe:PARAMeter}
\event{Sets the measurement parameter that is stored in the trace}{VNA:TRACe:PARAMeter}{<trace>, either by name or by index\\<parameter>, options are S11, S12, S21 or S22}
\query{Queries the measurement parameter of a trace}{VNA:TRACe:PARAMeter?}{<trace>, either by name or by index}{S11, S12, S21 or S22}

\subsubsection{VNA:TRACe:TYPE}
\event{Sets the storage type of a trace}{VNA:TRACe:TYPE}{<trace>, either by name or by index\\<type>, options are OVERWRITE, MAXHOLD or MINHOLD}
\query{Queries the storage type of a trace}{VNA:TRACe:TYPE?}{<trace>, either by name or by index}{OVERWRITE, MAXHOLD or MINHOLD}

\subsubsection{VNA:CALibration:ACTivate}
\event{Activates a specific calibration. This command fails if the required measurements have not been taken yet}{VNA:CALibration:ACTivate}{<type>}
\query{Queries the currently available calibration types}{VNA:CALibration:ACTivate?}{None}{comma-separated list of available calibration types}

\subsubsection{VNA:CALibration:ACTIVE}
\query{Queries the currently active calibration type}{VNA:CALibration:ACTIVE?}{None}{Currently active calibration type}

\subsubsection{VNA:CALibration:NUMber}
\query{Queries the number of available calibration measurements}{VNA:CALibration:NUMber?}{None}{<number of configured measurements>}

\subsubsection{VNA:CALibration:RESET}
\event{Resets the calibration. Deactivates the calibration and deletes all measurements.}{VNA:CALibration:RESET}{None}

\subsubsection{VNA:CALibration:ADD}
\event{Adds a new empty calibration measurement.}{VNA:CALibration:ADD}{<type> Measurement type, one of:\\
\hspace{1cm}OPEN\\
\hspace{1cm}SHORT\\
\hspace{1cm}LOAD\\
\hspace{1cm}THROUGH\\
\hspace{1cm}ISOLATION\\
\hspace{1cm}SLIDINGLOAD\\
\hspace{1cm}REFLECT\\
\hspace{1cm}LINE\\
{[<standard>]}, calibration kit standard name, optional\\}

\subsubsection{VNA:CALibration:TYPE}
\query{Returns the type of the specified measurement}{VNA:CALibration:TYPE?}{<measurement number>}{Measurement type, one of:\\
\hspace{1cm}OPEN\\
\hspace{1cm}SHORT\\
\hspace{1cm}LOAD\\
\hspace{1cm}THROUGH\\
\hspace{1cm}ISOLATION\\
\hspace{1cm}SLIDINGLOAD\\
\hspace{1cm}REFLECT\\
\hspace{1cm}LINE\\}

\subsubsection{VNA:CALibration:PORT}
\event{Sets the port for the specified measurement}{VNA:CALibration:PORT}{<measurement number> <port number>}
\query{Returns the port for the specified measurement}{VNA:CALibration:PORT?}{<measurement number>}{<port number>}

\subsubsection{VNA:CALibration:STANDARD}
\event{Sets the calibration standard which will be used for the specified measurement}{VNA:CALibration:STANDARD}{<measurement number> <standard name>}
\query{Returns the standard name for the specified measurement}{VNA:CALibration:STANDARD?}{<measurement number>}{Name of used calibration standard (from calibration kit)}

\subsubsection{VNA:CALibration:MEASure}
\event{Starts a calibration measurement. This command fails if no device is connected, the VNA mode is not active or a calibration measurement is already in progress.}{VNA:CALibration:MEASure}{<measurement 1>,<measurement 2>,...}
Any number of measurements can be specified (by their number). These measurements will be taken simultaneously. This only works if they are measuring different ports (e.g. measure SHORT on port 1 and OPEN on port 2). If colliding measurements are specified (e.g. SHORT on port 1 and LOAD on port 1), an error is returned and no measurements are started.

\subsubsection{VNA:CALibration:BUSY}
\query{Queries whether a calibration measurement is ongoing}{VNA:CALibration:BUSY?}{None}{TRUE or FALSE}

\subsubsection{VNA:CALibration:SAVE}
\event{Saves the active calibration to a file}{VNA:CALibration:SAVE}{<filename>}
Important points when saving/loading calibration files through SCPI commands:
\begin{itemize}
\item Filenames must be either absolute or relative to the location of the GUI application.
\item If the LibreVNA-GUI (and thus also the SCPI server) is running on a different machine than the SCPI client, the calibration files will be saved/loaded from the machine that runs the GUI.
\end{itemize}

\subsubsection{VNA:CALibration:LOAD}
\query{Loads a calibration file}{VNA:CALibration:LOAD?}{<filename>}{TRUE or FALSE}

\subsubsection{VNA:CALibration:KIT:MANufacturer}
\event{Sets the manufacturer name of the calibration kit}{VNA:CALibration:KIT:MANufacturer}{<manufacturer>}
\query{Returns the manufacturer name of the calibration kit}{VNA:CALibration:KIT:MANufacturer?}{None}{<manufacturer>}

\subsubsection{VNA:CALibration:KIT:SERial}
\event{Sets the serial number of the calibration kit}{VNA:CALibration:KIT:SERial}{<serial number>}
\query{Returns the serial number of the calibration kit}{VNA:CALibration:KIT:SERial?}{None}{<serial number>}

\subsubsection{VNA:CALibration:KIT:DESCription}
\event{Sets the description of the calibration kit}{VNA:CALibration:KIT:DESCription}{<description>}
\query{Returns the description of the calibration kit}{VNA:CALibration:KIT:DESCription?}{None}{<description>}

\subsubsection{VNA:CALibration:KIT:FILEname}
\query{Returns the filename of the calibration kit}{VNA:CALibration:KIT:FILEname?}{None}{<filename>}

The filename is only available if the calibration kit was loaded from a dedicated file. If it was loaded as part of a calibration file or has not been loaded since the GUI started, no filename will be returned.

\subsubsection{VNA:CALibration:KIT:SAVE}
\event{Saves the active calibration kit to a file}{VNA:CALibration:KIT:SAVE}{<filename>}
Important points when saving/loading calibration kit files through SCPI commands:
\begin{itemize}
\item Filenames must be either absolute or relative to the location of the GUI application.
\item If the LibreVNA-GUI (and thus also the SCPI server) is running on a different machine than the SCPI client, the calibration kit files will be saved/loaded from the machine that runs the GUI.
\end{itemize}

\subsubsection{VNA:CALibration:KIT:LOAD}
\query{Loads a calibration kit file}{VNA:CALibration:KIT:LOAD?}{<filename>}{TRUE or FALSE}

\subsubsection{Common calibration kit standards commands}
The calibration kit supports an arbitrary amount of standards. This requires a flexible SCPI API which adjusts to the currently configured standards.

A few calibration kit standard commands are always available and they can be used to create and delete calibration standards. Every created calibration standard adds their own commands. They can be accessed by including the calibration standard number in the command (shown as ``x'' in the following commands).

\subsubsubsection{VNA:CALibration:KIT:STAndard:CLEAR}
\event{Resets the calibration kit to default values (ideal standards)}{VNA:CALibration:KIT:STAndard:CLEAR}{None}

\subsubsubsection{VNA:CALibration:KIT:STAndard:NUMber}
\query{Returns the number of configured calibration standards}{VNA:CALibration:KIT:STAndard:NUMber?}{None}{<number of calibration standards>}

\subsubsubsection{VNA:CALibration:KIT:STAndard:TYPE}
\query{Returns the type of a created calibration standard}{VNA:CALibration:KIT:STAndard:TYPE?}{<x> Number of calibration standard}{Type of standard, one of:\\
\hspace{1cm}Open\\
\hspace{1cm}Short\\
\hspace{1cm}Load\\
\hspace{1cm}Reflect\\
\hspace{1cm}Through\\
\hspace{1cm}Line\\}

\subsubsubsection{VNA:CALibration:KIT:STAndard:NEW}
\event{Adds a new calibration standard}{VNA:CALibration:KIT:STAndard:NEW}{<type> Type of calibration standard, one of:\\
\hspace{1cm}Open\\
\hspace{1cm}Short\\
\hspace{1cm}Load\\
\hspace{1cm}Reflect\\
\hspace{1cm}Through\\
\hspace{1cm}Line\\
<name> User selectable name of new standard}

\subsubsubsection{VNA:CALibration:KIT:STAndard:DELete}
\event{Removes a calibration standard}{VNA:CALibration:KIT:STAndard:DELete}{<x> Number of standard to delete}

\subsubsection{OPEN standard commands}
The following commands are only valid for a calibration standard of type ``Open''. The ``x'' in the command names must be replaced with the calibration standard number.

\subsubsubsection{VNA:CALibration:KIT:STAndard:x:NAME}
\event{Sets the name of the standard}{VNA:CALibration:KIT:STAndard:x:NAME}{<name> User selectable name}
\query{Queries the name of the standard}{VNA:CALibration:KIT:STAndard:x:NAME?}{None}{<name> User selectable name}

\subsubsubsection{VNA:CALibration:KIT:STAndard:x:Z0}
\event{Sets the characteristic impedance of the standard}{VNA:CALibration:KIT:STAndard:x:Z0}{<Z> Characteristic impedance in Ohm}
\query{Queries the characteristic impedance of the standard}{VNA:CALibration:KIT:STAndard:x:Z0?}{None}{<Z> Characteristic impedance in Ohm}

\subsubsubsection{VNA:CALibration:KIT:STAndard:x:DELAY}
\event{Sets the delay of the standard}{VNA:CALibration:KIT:STAndard:x:DELAY}{<delay> Delay in \unit{\pico\second}}
\query{Queries the delay of the standard}{VNA:CALibration:KIT:STAndard:x:DELAY?}{None}{<delay> Delay in \unit{\pico\second}}

\subsubsubsection{VNA:CALibration:KIT:STAndard:x:LOSS}
\event{Sets the loss of the standard}{VNA:CALibration:KIT:STAndard:x:LOSS}{<loss> Loss in \unit{\giga\ohm\per\second}}
\query{Queries the loss of the standard}{VNA:CALibration:KIT:STAndard:x:LOSS?}{None}{<loss> Loss in \unit{\giga\ohm\per\second}}

\subsubsubsection{VNA:CALibration:KIT:STAndard:x:C0}
\event{Sets the fringing capacitance polynom term 0 of the standard}{VNA:CALibration:KIT:STAndard:x:C0}{<C0> in \num{d-15}\unit{\farad}}
\query{Queries the fringing capacitance polynom term 0 of the standard}{VNA:CALibration:KIT:STAndard:x:C0?}{None}{<C0> in \num{d-15}\unit{\farad}}

\subsubsubsection{VNA:CALibration:KIT:STAndard:x:C1}
\event{Sets the fringing capacitance polynom term 1 of the standard}{VNA:CALibration:KIT:STAndard:x:C1}{<C1> in \num{d-27}\unit{\farad\per\hertz}}
\query{Queries the fringing capacitance polynom term 1 of the standard}{VNA:CALibration:KIT:STAndard:x:C1?}{None}{<C1> in \num{d-27}\unit{\farad\per\hertz}}

\subsubsubsection{VNA:CALibration:KIT:STAndard:x:C2}
\event{Sets the fringing capacitance polynom term 2 of the standard}{VNA:CALibration:KIT:STAndard:x:C2}{<C2> in \num{d-36}\unit{\farad\per\hertz\squared}}
\query{Queries the fringing capacitance polynom term 2 of the standard}{VNA:CALibration:KIT:STAndard:x:C2?}{None}{<C2> in \num{d-36}\unit{\farad\per\hertz\squared}}

\subsubsubsection{VNA:CALibration:KIT:STAndard:x:C3}
\event{Sets the fringing capacitance polynom term 3 of the standard}{VNA:CALibration:KIT:STAndard:x:C3}{<C3> in \num{d-45}\unit{\farad\per\hertz\cubed}}
\query{Queries the fringing capacitance polynom term 3 of the standard}{VNA:CALibration:KIT:STAndard:x:C3?}{None}{<C3> in \num{d-45}\unit{\farad\per\hertz\cubed}}

\subsubsubsection{VNA:CALibration:KIT:STAndard:x:FILE}
\event{Loads the coefficients for the calibration standard from a touchstone file}{VNA:CALibration:KIT:STAndard:x:FILE}{<filename>\\<port> sets the port from the file which is used to define the standard, optional}

\subsubsection{SHORT standard commands}
The following commands are only valid for a calibration standard of type ``Short''. The ``x'' in the command names must be replaced with the calibration standard number.

\subsubsubsection{VNA:CALibration:KIT:STAndard:x:NAME}
\event{Sets the name of the standard}{VNA:CALibration:KIT:STAndard:x:NAME}{<name> User selectable name}
\query{Queries the name of the standard}{VNA:CALibration:KIT:STAndard:x:NAME?}{None}{<name> User selectable name}

\subsubsubsection{VNA:CALibration:KIT:STAndard:x:Z0}
\event{Sets the characteristic impedance of the standard}{VNA:CALibration:KIT:STAndard:x:Z0}{<Z> Characteristic impedance in Ohm}
\query{Queries the characteristic impedance of the standard}{VNA:CALibration:KIT:STAndard:x:Z0?}{None}{<Z> Characteristic impedance in Ohm}

\subsubsubsection{VNA:CALibration:KIT:STAndard:x:DELAY}
\event{Sets the delay of the standard}{VNA:CALibration:KIT:STAndard:x:DELAY}{<delay> Delay in \unit{\pico\second}}
\query{Queries the delay of the standard}{VNA:CALibration:KIT:STAndard:x:DELAY?}{None}{<delay> Delay in \unit{\pico\second}}

\subsubsubsection{VNA:CALibration:KIT:STAndard:x:LOSS}
\event{Sets the loss of the standard}{VNA:CALibration:KIT:STAndard:x:LOSS}{<loss> Loss in \unit{\giga\ohm\per\second}}
\query{Queries the loss of the standard}{VNA:CALibration:KIT:STAndard:x:LOSS?}{None}{<loss> Loss in \unit{\giga\ohm\per\second}}

\subsubsubsection{VNA:CALibration:KIT:STAndard:x:L0}
\event{Sets the residual inductance polynom term 0 of the standard}{VNA:CALibration:KIT:STAndard:x:L0}{<L0> in \num{d-12}\unit{\henry}}
\query{Queries the residual inductance polynom term 0 of the standard}{VNA:CALibration:KIT:STAndard:x:L0?}{None}{<L0> in \num{d-12}\unit{\henry}}

\subsubsubsection{VNA:CALibration:KIT:STAndard:x:L1}
\event{Sets the residual inductance polynom term 1 of the standard}{VNA:CALibration:KIT:STAndard:x:L1}{<L1> in \num{d-24}\unit{\henry\per\hertz}}
\query{Queries the residual inductance polynom term 1 of the standard}{VNA:CALibration:KIT:STAndard:x:L1?}{None}{<L1> in \num{d-24}\unit{\henry\per\hertz}}

\subsubsubsection{VNA:CALibration:KIT:STAndard:x:L2}
\event{Sets the residual inductance polynom term 2 of the standard}{VNA:CALibration:KIT:STAndard:x:L2}{<L2> in \num{d-33}\unit{\henry\per\hertz\squared}}
\query{Queries the residual inductance polynom term 2 of the standard}{VNA:CALibration:KIT:STAndard:x:L2?}{None}{<L2> in \num{d-33}\unit{\henry\per\hertz\squared}}

\subsubsubsection{VNA:CALibration:KIT:STAndard:x:L3}
\event{Sets the residual inductance polynom term 3 of the standard}{VNA:CALibration:KIT:STAndard:x:L3}{<L3> in \num{d-42}\unit{\henry\per\hertz\cubed}}
\query{Queries the residual inductance polynom term 3 of the standard}{VNA:CALibration:KIT:STAndard:x:L3?}{None}{<L3> in \num{d-42}\unit{\henry\per\hertz\cubed}}

\subsubsubsection{VNA:CALibration:KIT:STAndard:x:FILE}
\event{Loads the coefficients for the calibration standard from a touchstone file}{VNA:CALibration:KIT:STAndard:x:FILE}{<filename>\\<port> sets the port from the file which is used to define the standard, optional}

\subsubsection{LOAD standard commands}
The following commands are only valid for a calibration standard of type ``Load''. The ``x'' in the command names must be replaced with the calibration standard number.

\subsubsubsection{VNA:CALibration:KIT:STAndard:x:NAME}
\event{Sets the name of the standard}{VNA:CALibration:KIT:STAndard:x:NAME}{<name> User selectable name}
\query{Queries the name of the standard}{VNA:CALibration:KIT:STAndard:x:NAME?}{None}{<name> User selectable name}

\subsubsubsection{VNA:CALibration:KIT:STAndard:x:RESistance}
\event{Sets the resistance of the standard}{VNA:CALibration:KIT:STAndard:x:RESistance}{<R> in \unit{\ohm}}
\query{Queries the resistance of the standard}{VNA:CALibration:KIT:STAndard:x:RESistance?}{None}{<R> in \unit{\ohm}}

\subsubsubsection{VNA:CALibration:KIT:STAndard:x:Z0}
\event{Sets the characteristic impedance of the standard}{VNA:CALibration:KIT:STAndard:x:Z0}{<Z> Characteristic impedance in Ohm}
\query{Queries the characteristic impedance of the standard}{VNA:CALibration:KIT:STAndard:x:Z0?}{None}{<Z> Characteristic impedance in Ohm}

\subsubsubsection{VNA:CALibration:KIT:STAndard:x:DELAY}
\event{Sets the delay of the standard}{VNA:CALibration:KIT:STAndard:x:DELAY}{<delay> Delay in \unit{\pico\second}}
\query{Queries the delay of the standard}{VNA:CALibration:KIT:STAndard:x:DELAY?}{None}{<delay> Delay in \unit{\pico\second}}

\subsubsubsection{VNA:CALibration:KIT:STAndard:x:LOSS}
\event{Sets the loss of the standard}{VNA:CALibration:KIT:STAndard:x:LOSS}{<loss> Loss in \unit{\giga\ohm\per\second}}
\query{Queries the loss of the standard}{VNA:CALibration:KIT:STAndard:x:LOSS?}{None}{<loss> Loss in \unit{\giga\ohm\per\second}}

\subsubsubsection{VNA:CALibration:KIT:STAndard:x:CARallel}
\event{Sets the residual capacitance polynom of the standard}{VNA:CALibration:KIT:STAndard:x:CARallel}{<C> in \unit{\farad}}
\query{Queries the residual capacitance of the standard}{VNA:CALibration:KIT:STAndard:x:CARallel?}{None}{<C> in \unit{\farad}}

\subsubsubsection{VNA:CALibration:KIT:STAndard:x:LSERies}
\event{Sets the residual inductance of the standard}{VNA:CALibration:KIT:STAndard:x:LSERies}{<L> in \unit{\henry}}
\query{Queries the residual inductance of the standard}{VNA:CALibration:KIT:STAndard:x:LSERies?}{None}{<L> in \unit{\henry}}

\subsubsubsection{VNA:CALibration:KIT:STAndard:x:CFIRST}
\event{Sets the order of residual capacitance/inductance}{VNA:CALibration:KIT:STAndard:x:CFIRST}{TRUE or FALSE}
\query{Queries the order of residual capacitance/inductance}{VNA:CALibration:KIT:STAndard:x:CFIRST?}{None}{TRUE or FALSE}

\subsubsubsection{VNA:CALibration:KIT:STAndard:x:FILE}
\event{Loads the coefficients for the calibration standard from a touchstone file}{VNA:CALibration:KIT:STAndard:x:FILE}{<filename>\\<port> sets the port from the file which is used to define the standard, optional}

\subsubsection{REFLECT standard commands}
The following commands are only valid for a calibration standard of type ``Reflect''. The ``x'' in the command names must be replaced with the calibration standard number.

\subsubsubsection{VNA:CALibration:KIT:STAndard:x:NAME}
\event{Sets the name of the standard}{VNA:CALibration:KIT:STAndard:x:NAME}{<name> User selectable name}
\query{Queries the name of the standard}{VNA:CALibration:KIT:STAndard:x:NAME?}{None}{<name> User selectable name}

\subsubsubsection{VNA:CALibration:KIT:STAndard:x:SHORT}
\event{Sets the type of reflection standard}{VNA:CALibration:KIT:STAndard:x:SHORT}{TRUE for short standard or FALSE for open standard}
\query{Queries the type of reflection standard}{VNA:CALibration:KIT:STAndard:x:SHORT?}{None}{TRUE for short standard or FALSE for open standard}

\subsubsection{THROUGH standard commands}
The following commands are only valid for a calibration standard of type ``Through''. The ``x'' in the command names must be replaced with the calibration standard number.

\subsubsubsection{VNA:CALibration:KIT:STAndard:x:NAME}
\event{Sets the name of the standard}{VNA:CALibration:KIT:STAndard:x:NAME}{<name> User selectable name}
\query{Queries the name of the standard}{VNA:CALibration:KIT:STAndard:x:NAME?}{None}{<name> User selectable name}

\subsubsubsection{VNA:CALibration:KIT:STAndard:x:Z0}
\event{Sets the characteristic impedance of the standard}{VNA:CALibration:KIT:STAndard:x:Z0}{<Z> Characteristic impedance in Ohm}
\query{Queries the characteristic impedance of the standard}{VNA:CALibration:KIT:STAndard:x:Z0?}{None}{<Z> Characteristic impedance in Ohm}

\subsubsubsection{VNA:CALibration:KIT:STAndard:x:DELAY}
\event{Sets the delay of the standard}{VNA:CALibration:KIT:STAndard:x:DELAY}{<delay> Delay in \unit{\pico\second}}
\query{Queries the delay of the standard}{VNA:CALibration:KIT:STAndard:x:DELAY?}{None}{<delay> Delay in \unit{\pico\second}}

\subsubsubsection{VNA:CALibration:KIT:STAndard:x:LOSS}
\event{Sets the loss of the standard}{VNA:CALibration:KIT:STAndard:x:LOSS}{<loss> Loss in \unit{\giga\ohm\per\second}}
\query{Queries the loss of the standard}{VNA:CALibration:KIT:STAndard:x:LOSS?}{None}{<loss> Loss in \unit{\giga\ohm\per\second}}

\subsubsubsection{VNA:CALibration:KIT:STAndard:x:FILE}
\event{Loads the coefficients for the calibration standard from a touchstone file}{VNA:CALibration:KIT:STAndard:x:FILE}{<filename>\\
<port1> selects the first port from the file which is used to define the standard\\
<port1> selects the second port from the file which is used to define the standard}

\subsubsection{LINE standard commands}
The following commands are only valid for a calibration standard of type ``Line''. The ``x'' in the command names must be replaced with the calibration standard number.

\subsubsubsection{VNA:CALibration:KIT:STAndard:x:NAME}
\event{Sets the name of the standard}{VNA:CALibration:KIT:STAndard:x:NAME}{<name> User selectable name}
\query{Queries the name of the standard}{VNA:CALibration:KIT:STAndard:x:NAME?}{None}{<name> User selectable name}

\subsubsubsection{VNA:CALibration:KIT:STAndard:x:Z0}
\event{Sets the characteristic impedance of the standard}{VNA:CALibration:KIT:STAndard:x:Z0}{<Z> Characteristic impedance in Ohm}
\query{Queries the characteristic impedance of the standard}{VNA:CALibration:KIT:STAndard:x:Z0?}{None}{<Z> Characteristic impedance in Ohm}

\subsubsubsection{VNA:CALibration:KIT:STAndard:x:DELAY}
\event{Sets the delay of the standard}{VNA:CALibration:KIT:STAndard:x:DELAY}{<delay> Delay in \unit{\pico\second}}
\query{Queries the delay of the standard}{VNA:CALibration:KIT:STAndard:x:DELAY?}{None}{<delay> Delay in \unit{\pico\second}}

\subsubsubsection{VNA:CALibration:KIT:STAndard:x:FILE}
\event{Loads the coefficients for the calibration standard from a touchstone file}{VNA:CALibration:KIT:STAndard:x:FILE}{<filename>\\
<port1> selects the first port from the file which is used to define the standard\\
<port1> selects the second port from the file which is used to define the standard}

\subsubsection{Common Deembedding Commands}
The VNA supports various deembedding options which can also be configured through the SCPI API. Because the deembedding system is flexible and supports any number of deembedding options at the same time, the SCPI API is also flexible. Instead of fixed commands, the available commands change depending on the configured deembedding options.

A few deembedding commands are always available and they can be used to create, delete and swap deembedding options. Every created deembedding option adds their own commands. They can be accessed by including the option number in the command (shown as ``x'' in the following commands).

\subsubsubsection{VNA:DEEMBedding:NUMber}
\query{Returns the number of configured deembedding options}{VNA:DEEMBedding:NUMber?}{None}{<number of deembedding options>}

\subsubsubsection{VNA:DEEMBedding:TYPE}
\query{Returns the type of a configured deembedding option}{VNA:DEEMBedding:TYPE?}{<x> Number of deembedding option}{Type of option, one of:\\
\hspace{1cm}Port\_Extension\\
\hspace{1cm}2xThru\\
\hspace{1cm}Matching\_Network\\
\hspace{1cm}Impedance\_Renormalization\\}

\subsubsubsection{VNA:DEEMBedding:NEW}
\event{Adds a new deembedding option}{VNA:DEEMBedding:NEW}{<type> Type of option, one of:\\
\hspace{1cm}Port\_Extension\\
\hspace{1cm}2xThru\\
\hspace{1cm}Matching\_Network\\
\hspace{1cm}Impedance\_Renormalization\\}

\subsubsubsection{VNA:DEEMBedding:DELete}
\event{Removes a deembedding option}{VNA:DEEMBedding:DELete}{<x> Number of option to delete}

\subsubsubsection{VNA:DEEMBedding:SWAP}
\event{Swaps the order of two deembedding options}{VNA:DEEMBedding:SWAP}{<x1> Number of option 1 to swap\\<x2> Number of option 2 to swap}

\subsubsubsection{VNA:DEEMBedding:CLEAR}
\event{Delete all deembedding options}{VNA:DEEMBedding:CLEAR}{None}

\subsubsection{Port Extension Deembedding Commands}
The following commands are only valid for a deembedding option of type ``Port\_Extension''. The ``x'' in the command names must be replaced with the option number.

\subsubsubsection{VNA:DEEMBedding:x:PORT}
\event{Sets the port}{VNA:DEEMBedding:x:PORT}{<port>, 1...n}
\query{Queries the selected port}{VNA:DEEMBedding:x:PORT?}{None}{<port>, 1...n}

\subsubsubsection{VNA:DEEMBedding:x:DELAY}
\event{Sets the delay of the port extension}{VNA:DEEMBedding:x:DELAY}{<delay> Delay in seconds}
\query{Queries the delay of the port extension}{VNA:DEEMBedding:x:DELAY?}{None}{<delay> Delay in seconds}

\subsubsubsection{VNA:DEEMBedding:x:DCLOSS}
\event{Sets the DC loss of the port extension}{VNA:DEEMBedding:x:DCLOSS}{<loss> Loss at DC in dB}
\query{Queries the DC loss of the port extension}{VNA:DEEMBedding:x:DCLOSS?}{None}{<loss> Loss at DC in dB}

\subsubsubsection{VNA:DEEMBedding:x:LOSS}
\event{Sets the loss of the port extension at the configured frequency}{VNA:DEEMBedding:x:LOSS}{<loss> Loss at frequency in dB}
\query{Queries the loss of the port extension at the configured frequency}{VNA:DEEMBedding:x:LOSS?}{None}{<loss> Loss at frequency in dB}

\subsubsubsection{VNA:DEEMBedding:x:FREQuency}
\event{Sets the frequency for the specified loss of the port extension}{VNA:DEEMBedding:x:FREQuency}{<freq> Frequency for loss in Hz}
\query{Queries the frequency for the specified loss of the port extension}{VNA:DEEMBedding:x:FREQuency?}{None}{<freq> Frequency for loss in Hz}

\subsubsection{2xThru Deembedding Commands}
The 2xThru deembedding does not have a SCPI API so far because it requires the user to manually make specific connections and take additional measurements.

\subsubsection{Matching Network Deembedding Commands}
The following commands are only valid for a deembedding option of type ``Matching\_Network''. The ``x'' in the command names must be replaced with the option number.

Similarly to the deembedding options, the matching network itself is also flexible and requires a flexible API as well. A similar approach is used where components in the matching network are given a number. This number is shown as ``y'' in the following commands.

\subsubsubsection{VNA:DEEMBedding:x:PORT}
\event{Sets the port at which the matching network is added}{VNA:DEEMBedding:x:PORT}{<port>, 1...n}
\query{Queries the port at which the matching network is added}{VNA:DEEMBedding:x:PORT?}{None}{<port>, 1...n}

\subsubsubsection{VNA:DEEMBedding:x:ADD}
\event{Selects whether the network is added or removed during the deembedding}{VNA:DEEMBedding:x:ADD}{TRUE if the effect of the network should be added. FALSE if the effect of the\\
\hspace{1cm}network should be subtracted}
\query{Queries whether the network is added or removed during the deembedding}{VNA:DEEMBedding:x:ADD?}{None}{TRUE or FALSE}

\subsubsubsection{VNA:DEEMBedding:x:NUMber}
\query{Returns the number of configured matching network components}{VNA:DEEMBedding:x:NUMber?}{None}{<number of matching network components>}

\subsubsubsection{VNA:DEEMBedding:x:TYPE}
\query{Returns the type of a configured matching network component}{VNA:DEEMBedding:x:TYPE? <y>}{<y> Number of matching component}{Type of component, one of:\\
\hspace{1cm}SeriesR\\
\hspace{1cm}SeriesL\\
\hspace{1cm}SeriesC\\
\hspace{1cm}ParallelR\\
\hspace{1cm}ParallelL\\
\hspace{1cm}ParallelC\\
\hspace{1cm}Touchstone\_Through\\
\hspace{1cm}Touchstone\_Shunt\\}

\subsubsubsection{VNA:DEEMBedding:x:NEW}
\event{Adds a new matching network component}{VNA:DEEMBedding:x:NEW}{<type> Type of component, one of:\\
\hspace{1cm}SeriesR\\
\hspace{1cm}SeriesL\\
\hspace{1cm}SeriesC\\
\hspace{1cm}ParallelR\\
\hspace{1cm}ParallelL\\
\hspace{1cm}ParallelC\\
\hspace{1cm}Touchstone\_Through\\
\hspace{1cm}Touchstone\_Shunt\\
<pos> position at which the component will be added. A value of 0 adds the\\
\hspace{1cm}component closest to the port. This parameter is optional. If it is omitted,\\
\hspace{1cm}the component is added closest to the DUT}

\subsubsubsection{VNA:DEEMBedding:x:DELete}
\event{Removes a matching network component}{VNA:DEEMBedding:x:DELete}{<y> Number of component to delete}

\subsubsubsection{VNA:DEEMBedding:x:CLEAR}
\event{Removes all matching network components}{VNA:DEEMBedding:x:DELete}{None}

\subsubsection{Impedance Renormalization Deembedding Commands}
The following commands are only valid for a deembedding option of type ``Impedance\_Renormalization''. The ``x'' in the command names must be replaced with the option number.

\subsubsubsection{VNA:DEEMBedding:x:IMPedance}
\event{Sets the target impedance}{VNA:DEEMBedding:x:IMPedance}{<impedance> Impedance in Ohm}
\query{Queries the target impedance}{VNA:DEEMBedding:x:IMPedance?}{None}{<impedance> Impedance in Ohm}

\subsubsubsection{VNA:DEEMBedding:x:y:VALue}
\event{Sets the value of a matching network component}{VNA:DEEMBedding:x:y:VALue}{<value>, either in Ohm, Farad or Henry}
\query{Queries the value of a matching network component}{VNA:DEEMBedding:x:y:VALue?}{None}{<port>, either in Ohm, Farad or Henry}

This command is only available for a component of these types:
\begin{itemize}
\item SeriesR
\item SeriesL
\item SeriesC
\item ParallelR
\item ParallelL
\item ParallelC
\end{itemize}

\subsubsubsection{VNA:DEEMBedding:x:y:FILE}
\event{Loads a matching network component values from a Touchstone file}{VNA:DEEMBedding:x:y:FILE}{<filename>}

This command is only available for a component of these types:
\begin{itemize}
\item Touchstone\_Through
\item Touchstone\_Shunt
\end{itemize}

\subsection{Signal Generator Commands}
These commands change or query signal generator settings. Although most of them are available regardless of the current device mode, they usually only have an effect once the generator mode is active.

\subsubsection{GENerator:FREQuency}
\event{Sets the output frequeny}{GENerator:FREQuency}{<frequency>, in Hz}
\query{Queries the selected output frequency}{GENerator:FREQuency?}{None}{frequency in Hz}

\subsubsection{GENerator:LVL}
\event{Sets the output power}{GENerator:LVL}{<output level>, in dBm}
\query{Queries the selected output power}{GENerator:LVL?}{None}{output level in dBm}

\subsubsection{GENerator:PORT}
\event{Sets the active output port}{GENerator:PORT}{<output port>\\
\hspace{1cm}0: output disabled\\
\hspace{1cm}1: output signal at port 1\\
\hspace{1cm}2: output signal at port 2\\}
\query{Queries the selected output}{GENerator:PORT?}{None}{output port}

\subsection{Spectrum Analyzer Commands}
These commands change or query spectrum analyzer settings. Although most of them are available regardless of the current device mode, they usually only have an effect once the spectrum analyzer mode is active.

\subsubsection{SA:FREQuency:SPAN}
\event{Sets the span of the sweep}{SA:FREQuency:SPAN}{<span>, in Hz}
\query{Queries the currently selected span}{SA:FREQuency:SPAN?}{None}{span in Hz}

\subsubsection{SA:FREQuency:START}
\event{Sets the start frequency of the sweep}{SA:FREQuency:START}{<start frequency>, in Hz}
\query{Queries the currently selected start frequency}{SA:FREQuency:START?}{None}{start frequency in Hz}

\subsubsection{SA:FREQuency:CENTer}
\event{Sets the center frequency of the sweep}{SA:FREQuency:CENTer}{<center frequency>, in Hz}
\query{Queries the currently selected center frequency}{SA:FREQuency:CENTer?}{None}{center frequency in Hz}

\subsubsection{SA:FREQuency:STOP}
\event{Sets the stop frequency of the sweep}{SA:FREQuency:STOP}{<stop frequency>, in Hz}
\query{Queries the currently selected stop frequency}{SA:FREQuency:STOP?}{None}{stop frequency in Hz}

\subsubsection{SA:FREQuency:FULL}
\event{Sets the device to the maximum span possible}{SA:FREQuency:FULL}{None}

\subsubsection{SA:FREQuency:ZERO}
\event{Sets the device to zero span mode}{SA:FREQuency:ZERO}{None}

\subsubsection{SA:ACQuisition:RUN}
\event{Puts the spectrum analyzer into run mode (sweep active)}{SA:ACQuisition:RUN}{None}
\query{Queries whether the spectrum analyzer is in run mode}{SA:ACQuisition:RUN?}{None}{TRUE or FALSE}

\subsubsection{SA:ACQuisition:STOP}
\event{Puts the spectrum analyzer into stop mode (sweep inactive)}{SA:ACQuisition:STOP}{None}

\subsubsection{SA:ACQuisition:RBW}
\event{Sets the resolution bandwidth}{SA:ACQuisition:IFBW}{<resolution bandwidth>, in Hz}
\query{Queries the currently selected resolution bandwidth}{SA:ACQuisition:IFBW?}{None}{resolution bandwidth in Hz}

\subsubsection{SA:ACQuisition:WINDow}
\event{Sets the type of window used in the acquisition}{SA:ACQuisition:WINDow}{<windowtype>\\
\hspace{1cm}NONE\\
\hspace{1cm}KAISER\\
\hspace{1cm}HANN\\
\hspace{1cm}FLATTOP\\
}
\query{Queries the currently selected type of window}{SA:ACQuisition:WINDow?}{None}{NONE, KAISER, HANN or FLATTOP}

\subsubsection{SA:ACQuisition:DETector}
\event{Sets the detector type}{SA:ACQuisition:DETector}{<detector>\\
\hspace{1cm}+PEAK\\
\hspace{1cm}-PEAK\\
\hspace{1cm}NORMAL\\
\hspace{1cm}SAMPLE\\
\hspace{1cm}AVERAGE\\
}
\query{Queries the currently selected detector type}{SA:ACQuisition:DETector?}{None}{+PEAK, -PEAK, NORMAL, SAMPLE or AVERAGE}

\subsubsection{SA:ACQuisition:AVG}
\event{Sets the number of sweeps over which a moving average is calculated}{SA:ACQuisition:AVG}{<sweeps>}
\query{Queries the currently configured number of sweeps}{SA:ACQuisition:AVG?}{None}{sweeps}

\subsubsection{SA:ACQuisition:AVGLEVel}
\query{Queries the number of sweeps that have been acquired by the average function.}{SA:ACQuisition:AVGLEVel?}{None}{<acquired sweeps>}
<acquired sweeps> resets to zero whenever a setting is changed. It is incremented at the end of each sweep, but will not go above the number of configured sweeps for the averaging.

Example (assuming <averaging sweep> = 3):
\begin{longtable}{p{.2\textwidth} | p{.2\textwidth} }
\textbf{\# of active sweep} & \textbf{<acquired sweeps>}\\
\hline
1 & 0\\
2 & 1\\
3 & 2\\
4 & 3\\
5 & 3\\
\end{longtable}

\subsubsection{SA:ACQuisition:FINished}
\query{Queries whether the average filter has reached a steady state (that is <acquired sweeps> = <averaging sweeps>)}{SA:ACQuisition:FINished?}{None}{TRUE or FALSE}

\subsubsection{SA:ACQuisition:LIMit}
\query{Queries the status of limits that maybe set up on any graph}{SA:ACQuisition:LIMit?}{None}{PASS or FAIL}

\subsubsection{SA:ACQuisition:SINGLE}
\event{Configures the spectrum analyzer for single or continuous sweep}{SA:ACQuisition:SINGLE}{TRUE or FALSE}
\query{Queries whether the spectrum analyzer is set up for single sweep}{SA:ACQuisition:SINGLE?}{None}{TRUE or FALSE}

If single sweep is enabled, the acquisition is stopped when the required number of averages have been reached. There are two ways to trigger a new sweep:
\begin{itemize}
\item Change any sweep setting (e.g. center frequency)
\item Issue the command again (i.e. SA:ACQ:SINGLE TRUE always triggers a new sweep)
\end{itemize}

\subsubsection{SA:ACQuisition:SIGid}
\event{Enables/disables signal identification}{SA:ACQuisition:SIGid}{<enabled>, option are TRUE, FALSE, 1 or 0}
\query{Queries whether signal identification is enabled}{SA:ACQuisition:SIGid?}{None}{TRUE or FALSE}

\subsubsection{SA:ACQuisition:FREQuency}
\query{Returns the current frequency of the sweep}{SA:ACQuisition:FREQuency?}{None}{<Frequency in Hz>}

This command only returns valid data when a sweep is running and the the sweep is a frequency sweep.

\subsubsection{SA:ACQuisition:TIME}
\query{Returns the current time of the sweep}{SA:ACQuisition:TIME?}{None}{<Time in seconds>}

This command only returns valid data when a sweep is running and the the sweep is a zero-span sweep.

\subsubsection{SA:TRACKing:ENable}
\event{Enables/disables the tracking generator}{SA:TRACKing:ENable}{<enabled>, option are TRUE, FALSE, 1 or 0}
\query{Queries whether tracking generator is enabled}{SA:TRACKing:ENable?}{None}{TRUE or FALSE}

\subsubsection{SA:TRACKing:PORT}
\event{Sets the output port of the tracking generator}{SA:TRACKing:PORT}{<port>, either 1 or 2}
\query{Queries the output port of the tracking generator}{SA:TRACKing:PORT?}{None}{1 or 2}

\subsubsection{SA:TRACKing:LVL}
\event{Sets the output power of the tracking generator}{SA:TRACKing:LVL}{<output level>, in dBm}
\query{Queries the selected output power of the tracking generator}{SA:TRACKing:LVL?}{None}{output level in dBm}

\subsubsection{SA:TRACKing:OFFset}
\event{Sets the offset frequency of the tracking generator}{SA:TRACKing:OFFset}{<offset>, in Hz}
\query{Queries the selected offset frequency of the tracking generator}{SA:TRACKing:OFFset?}{None}{offset in Hz}

\subsubsection{SA:TRACKing:NORMalize:ENable}
\event{Enables/disables normalization. If the span has changed since the last active normalization, a normalization measurement is also started.}{SA:TRACKing:NORMalize:ENable}{<enabled>, option are TRUE, FALSE, 1 or 0}
\query{Queries whether tracking generator normalization is enabled}{SA:TRACKing:NORMalize:ENable?}{None}{TRUE or FALSE}

\subsubsection{SA:TRACKing:NORMalize:MEASure}
\event{Triggers a new normalization measurement}{SA:TRACKing:NORMalize:MEASure}{None}

\subsubsection{SA:TRACKing:NORMalize:LVL}
\event{Sets the reference level for the normalization}{SA:TRACKing:NORMalize:LVL}{<normalization level>, in dBm}
\query{Queries the selected reference level for the normalization}{SA:TRACKing:NORMalize:LVL?}{None}{normalization level in dBm}

\subsubsection{SA:TRACe:LIST}
\query{Lists the names of all available traces}{SA:TRACe:LIST?}{None}{comma-separated list of trace name}
\begin{example}
VNA:TRAC:LIST?
Port1,Port2
\end{example}

\subsubsection{SA:TRACe:DATA}
\query{Returns the data of a trace}{SA:TRACe:DATA?}{<trace>, either by name or by index}{comma-separated list of tuples [x, dBm]}
\begin{example}
:SA:TRACE:DATA? PORT1
[9.75e+8,-100.351],
[9.7505e+8,-95.7394],
[9.751e+8,-97.5749],
[9.7515e+8,-96.9667],
[9.752e+8,-96.2391],
[9.7525e+8,-94.8761],
[9.753e+8,-96.0805],
[9.7535e+8,-95.7997],
[9.754e+8,-95.2021],
[9.7545e+8,-96.3472]
\end{example}
\vspace{-0.6cm}
\begin{center}
\footnotesize{Note: actual response will not include newlines between data points, only at the end}\\
\end{center}

\subsubsection{SA:TRACe:AT}
\query{Returns the data at a specific frequency (possibly interpolated)}{SA:TRACe:AT?}{<trace>, either by name or by index\\<frequency>, in Hz}{<dBm> or ``NaN'' if specified frequeny is invalid)}
\begin{example}
:SA:TRAC:AT? Port1 1000000000
-96.424
\end{example}

\subsubsection{SA:TRACe:MAXFrequency}
\query{Returns the highest frequency contained in the trace}{SA:TRACe:MAXFrequency?}{<trace>, either by name or by index}{maximum frequency in Hz}

\subsubsection{SA:TRACe:MINFrequency}
\query{Returns the lowest frequency contained in the trace}{SA:TRACe:MINFrequency?}{<trace>, either by name or by index}{maximum frequency in Hz}

\subsubsection{SA:TRACe:MAXAmplitude}
\query{Returns the datapoint with the highest amplitude in the trace}{SA:TRACe:MAXAmplitude?}{<trace>, either by name or by index}{<frequency>,<dBm> of the highest amplitude point}
\begin{example}
:SA:TRAC:MAXA? Port1
9.63e+8,-12.534
\end{example}

\subsubsection{SA:TRACe:MINAmplitude}
\query{Returns the datapoint with the lowest amplitude in the trace}{SA:TRACe:MINAmplitude?}{<trace>, either by name or by index}{<frequency>,<dBm> of the lowest amplitude point}

\subsubsection{SA:TRACe:NEW}
\event{Creates a new trace}{SA:TRACe:NEW}{<trace name>}

\subsubsection{SA:TRACe:DELete}
\event{Deletes a trace}{VNA:TRACe:DELete}{<trace>, either by name or by index}

\subsubsection{SA:TRACe:RENAME}
\event{Changes the name of a trace}{SA:TRACe:RENAME}{<trace>, either by name or by index\\<new name>}

\subsubsection{SA:TRACe:PAUSE}
\event{Pauses (freezes) a trace}{SA:TRACe:PAUSE}{<trace>, either by name or by index}

\subsubsection{SA:TRACe:RESUME}
\event{Resumes (unfreezes) a trace}{SA:TRACe:RESUME}{<trace>, either by name or by index}

\subsubsection{SA:TRACe:PAUSED}
\query{Queries whether a trace is paused}{SA:TRACe:PAUSED?}{<trace>, either by name or by index}{TRUE or FALSE}

\subsubsection{SA:TRACe:PARAMeter}
\event{Sets the measurement parameter that is stored in the trace}{SA:TRACe:PARAMeter}{<trace>, either by name or by index\\<parameter>, options are PORT1 and PORT2}
\query{Queries the measurement parameter of a trace}{SA:TRACe:PARAMeter?}{<trace>, either by name or by index}{PORT1 or PORT2}

\subsubsection{SA:TRACe:TYPE}
\event{Sets the storage type of a trace}{SA:TRACe:TYPE}{<trace>, either by name or by index\\<type>, options are OVERWRITE, MAXHOLD or MINHOLD}
\query{Queries the storage type of a trace}{SA:TRACe:TYPE?}{<trace>, either by name or by index}{OVERWRITE, MAXHOLD or MINHOLD}

\section{Custom Driver Commands}
The \gui{} is mainly intended to be used with the \vna{}. However, the interface between the \gui{} and the actual VNA is abstracting certain hardware features to allow the \gui{} to interact with other devices as well. This is mainly intended for future extensions and only very few other devices are supported for testing and demonstration purposes.

Each device driver may implement additional SCPI commands that are too specific to be useful with every device. These commands are only available when the \gui{} is connected to the device.

\subsection{LibreVNA Version 1}
The following commands are available when connected to a LibreVNA (hardware version 1):

\subsubsection{DEVice:UPDATE}
\event{Updates the firmware of the connected device}{DEVice:UPDATE <fw\_file>}{<fw\_file> Path to the firmware file}
Important points when saving/loading setup files through SCPI commands:
\begin{itemize}
\item The path must be either absolute or relative to the location of the GUI application.
\item If the LibreVNA-GUI (and thus also the SCPI server) is running on a different machine than the SCPI client, the firmware file must be stored on the machine that runs the GUI.
\end{itemize}

\subsubsection{DEVice:INFo:TEMPeratures}
\query{Queries the temperatures of certain chips}{DEVice:INFo:TEMPeratures?}{None}{<source>/<1.LO>/<CPU>}
\begin{example}
:DEV:INF:TEMP?
45/51/31
\end{example}

\subsubsection{MANual:STArt}
\event{Starts the manual device control dialog}{MANual:STArt}{None}

The manual device control dialog allows the user to directly access all the hardware components. This can be considered as a forth mode (in addition to VNA, signal generator and spectrum analyzer). As long as it is active, it takes priority over any other mode. After starting the manual control dialog, all hardware components are disabled by default. While the manual control dialog is active, additional SCPI commands are available to configure the hardware and retrieve ADC readings.

\subsubsection{MANual:STOp}
\event{Stops the manual device control dialog}{MANual:STOp}{None}

\subsubsection{MANual:HSRC\_CE}
Only available when the manual control dialog is active.

\event{Controls the chip enable for the highband source}{MANual:HSRC\_CE}{TRUE or FALSE}
\query{Queries the status of the chip enable for the highband source}{MANual:HSRC\_CE?}{None}{TRUE or FALSE}

\subsubsection{MANual:HSRC\_RFEN}
Only available when the manual control dialog is active.

\event{Controls the RF enable for the highband source}{MANual:HSRC\_RFEN}{TRUE or FALSE}
\query{Queries the status of the RF enable for the highband source}{MANual:HSRC\_RFEN?}{None}{TRUE or FALSE}

\subsubsection{MANual:HSRC\_LOCKed}
Only available when the manual control dialog is active.

\query{Queries the lock status of the highband source}{MANual:HSRC\_LOCKed?}{None}{TRUE or FALSE}

\subsubsection{MANual:HSRC\_PWR}
Only available when the manual control dialog is active.

\event{Sets the output power of the highband source}{MANual:HSRC\_PWR}{<power>, output power in dBm, allowed values are -4, -1, 2 and 5}
\query{Queries the output power of the highband source}{MANual:HSRC\_PWR?}{None}{<power>, output power in dBm}

\subsubsection{MANual:HSRC\_FREQ}
Only available when the manual control dialog is active.

\event{Sets the target frequency of the highband source}{MANual:HSRC\_FREQ}{<freq>, frequency in Hz}
\query{Queries the target frequency of the highband source}{MANual:HSRC\_FREQ?}{None}{<freq>, frequency in Hz}

\subsubsection{MANual:HSRC\_LPF}
Only available when the manual control dialog is active.

\event{Sets the lowpass filter of the highband source}{MANual:HSRC\_LPF}{<cutoff>, Cutoff frequency in MHz, allowed values are 947, 1880, 3500 and\\0 (no filter)}
\query{Queries the lowpass filter setting of the highband source}{MANual:HSRC\_LPF?}{None}{<cutoff>, Cutoff frequency in MHz}

\subsubsection{MANual:LSRC\_EN}
Only available when the manual control dialog is active.

\event{Controls the enable signal for the lowband source}{MANual:LSRC\_EN}{TRUE or FALSE}
\query{Queries the status of the enable signal for the lowband source}{MANual:LSRC\_EN?}{None}{TRUE or FALSE}

\subsubsection{MANual:LSRC\_PWR}
Only available when the manual control dialog is active.

\event{Sets the output power of the lowband source}{MANual:LSRC\_PWR}{<power>, output power in mA, allowed values are 2, 4, 6 and 8}
\query{Queries the output power of the lowband source}{MANual:LSRC\_PWR?}{None}{<power>, output power in mA}

\subsubsection{MANual:LSRC\_FREQ}
Only available when the manual control dialog is active.

\event{Sets the target frequency of the lowband source}{MANual:LSRC\_FREQ}{<freq>, frequency in Hz}
\query{Queries the target frequency of the lowband source}{MANual:LSRC\_FREQ?}{None}{<freq>, frequency in Hz}

\subsubsection{MANual:BAND\_SW}
Only available when the manual control dialog is active.

\event{Controls the band selector switch}{MANual:BAND\_SW}{TRUE for highband, FALSE for lowband}
\query{Queries the status of the band selector switch}{MANual:BAND\_SW?}{None}{TRUE for highband, FALSE for lowband}

\subsubsection{MANual:ATTenuator}
Only available when the manual control dialog is active.

\event{Sets the attenuator value}{MANual:ATTenuator}{<att>, Attenuation in dB, values between -31.75 and 0}
\query{Queries the attenuator value}{MANual:ATTenuator?}{None}{<att>, Attenuation in dB}

\subsubsection{MANual:AMP\_EN}
Only available when the manual control dialog is active.

\event{Controls the enable signal for the amplifier}{MANual:AMP\_EN}{TRUE or FALSE}
\query{Queries the status of the enable signal for the amplifier}{MANual:AMP\_EN?}{None}{TRUE or FALSE}

\subsubsection{MANual:PORT\_SW}
Only available when the manual control dialog is active.

\event{Controls the port selector switch}{MANual:PORT\_SW}{<port>, either 1 or 2}
\query{Queries the status of the port selector switch}{MANual:PORT\_SW?}{None}{<port>}

\subsubsection{MANual:LO1\_CE}
Only available when the manual control dialog is active.

\event{Controls the chip enable for the LO1 PLL}{MANual:LO1\_CE}{TRUE or FALSE}
\query{Queries the status of the chip enable for the LO1 PLL}{MANual:LO1\_CE?}{None}{TRUE or FALSE}

\subsubsection{MANual:LO1\_RFEN}
Only available when the manual control dialog is active.

\event{Controls the RF enable for the LO1 PLL}{MANual:LO1\_RFEN}{TRUE or FALSE}
\query{Queries the status of the RF enable for the LO1 PLL}{MANual:LO1\_RFEN?}{None}{TRUE or FALSE}

\subsubsection{MANual:LO1\_LOCKed}
Only available when the manual control dialog is active.

\query{Queries the lock status of the LO1 PLL}{MANual:LO1\_LOCKed?}{None}{TRUE or FALSE}

\subsubsection{MANual:LO1\_FREQ}
Only available when the manual control dialog is active.

\event{Sets the target frequency of the LO1 PLL}{MANual:LO1\_FREQ}{<freq>, frequency in Hz}
\query{Queries the target frequency of the LO1 PLL}{MANual:LO1\_FREQ?}{None}{<freq>, frequency in Hz}

\subsubsection{MANual:IF1\_FREQ}
Only available when the manual control dialog is active.

\event{Sets the IF1 frequency}{MANual:IF1\_FREQ}{<freq>, frequency in Hz}
\query{Queries the IF1 frequency}{MANual:IF1\_FREQ?}{None}{<freq>, frequency in Hz}

\subsubsection{MANual:LO2\_EN}
Only available when the manual control dialog is active.

\event{Controls the enable signal for the LO2 PLL}{MANual:LO2\_EN}{TRUE or FALSE}
\query{Queries the status of the enable signal for the LO2 PLL}{MANual:LO2\_EN?}{None}{TRUE or FALSE}

\subsubsection{MANual:LO2\_FREQ}
Only available when the manual control dialog is active.

\event{Sets the target frequency of the LO2 PLL}{MANual:LO2\_FREQ}{<freq>, frequency in Hz}
\query{Queries the target frequency of the LO2 PLL}{MANual:LO2\_FREQ?}{None}{<freq>, frequency in Hz}

\subsubsection{MANual:IF2\_FREQ}
Only available when the manual control dialog is active.

\event{Sets the IF2 frequency}{MANual:IF2\_FREQ}{<freq>, frequency in Hz}
\query{Queries the IF2 frequency}{MANual:IF2\_FREQ?}{None}{<freq>, frequency in Hz}

\subsubsection{MANual:PORT1\_EN}
Only available when the manual control dialog is active.

\event{Controls the enable signal for the port 1 receiver}{MANual:PORT1\_EN}{TRUE or FALSE}
\query{Queries the status of the enable signal for the port 1 receiver}{MANual:PORT1\_EN?}{None}{TRUE or FALSE}

\subsubsection{MANual:PORT2\_EN}
Only available when the manual control dialog is active.

\event{Controls the enable signal for the port 2 receiver}{MANual:PORT2\_EN}{TRUE or FALSE}
\query{Queries the status of the enable signal for the port 2 receiver}{MANual:PORT2\_EN?}{None}{TRUE or FALSE}

\subsubsection{MANual:REF\_EN}
Only available when the manual control dialog is active.

\event{Controls the enable signal for the reference receiver}{MANual:REF\_EN}{TRUE or FALSE}
\query{Queries the status of the enable signal for the reference receiver}{MANual:REF\_EN?}{None}{TRUE or FALSE}

\subsubsection{MANual:SAMPLES}
Only available when the manual control dialog is active.

\event{Sets the number of ADC samples per reading}{MANual:SAMPLES}{<samples>, value between 16 and 131072 in increments of 16}
\query{Queries the number of ADC samples per reading}{MANual:SAMPLES?}{None}{<samples>}

\subsubsection{MANual:WINdow}
Only available when the manual control dialog is active.

\event{Sets the window for the DFT calculation}{MANual:WINdow}{<window>, either NONE, KAISER, HANN or FLATTOP}
\query{Queries the window for the DFT calculatio}{MANual:WINdow?}{None}{NONE, KAISER, HANN or FLATTOP}

\subsubsection{MANual:PORT1\_MIN}
Only available when the manual control dialog is active.

\query{Queries the minimum observed port 1 ADC value in the last sampling period}{MANual:PORT1\_MIN?}{None}{minimum ADC value}

\subsubsection{MANual:PORT1\_MAX}
Only available when the manual control dialog is active.

\query{Queries the maximum observed port 1 ADC value in the last sampling period}{MANual:PORT1\_MAX?}{None}{maximum ADC value}

\subsubsection{MANual:PORT1\_MAG}
Only available when the manual control dialog is active.

\query{Queries the observerd magnitude at port 1 in the last sampling period}{MANual:PORT1\_MAG?}{None}{port 1 magnitude (linear unit, arbitrary scale)}

\subsubsection{MANual:PORT1\_PHAse}
Only available when the manual control dialog is active.

\query{Queries the observed phase at port 1 in the last sampling period}{MANual:PORT1\_PHAse?}{None}{phase in degree (random value because it is relativ to an internal sampling clock)}

\subsubsection{MANual:PORT1\_REFerenced}
Only available when the manual control dialog is active.

\query{Queries the observed signal at port 1 relative to the reference in the last sampling period}{MANual:PORT1\_REFerenced?}{None}{<real>, <imag>}

\subsubsection{MANual:PORT2\_MIN}
Only available when the manual control dialog is active.

\query{Queries the minimum observed port 2 ADC value in the last sampling period}{MANual:PORT2\_MIN?}{None}{minimum ADC value}

\subsubsection{MANual:PORT2\_MAX}
Only available when the manual control dialog is active.

\query{Queries the maximum observed port 2 ADC value in the last sampling period}{MANual:PORT2\_MAX?}{None}{maximum ADC value}

\subsubsection{MANual:PORT2\_MAG}
Only available when the manual control dialog is active.

\query{Queries the observerd magnitude at port 2 in the last sampling period}{MANual:PORT2\_MAG?}{None}{port 1 magnitude (linear unit, arbitrary scale)}

\subsubsection{MANual:PORT2\_PHAse}
Only available when the manual control dialog is active.

\query{Queries the observed phase at port 2 in the last sampling period}{MANual:PORT2\_PHAse?}{None}{phase in degree (random value because it is relativ to an internal sampling clock)}

\subsubsection{MANual:PORT2\_REFerenced}
Only available when the manual control dialog is active.

\query{Queries the observed signal at port 2 relative to the reference in the last sampling period}{MANual:PORT2\_REFerenced?}{None}{<real>, <imag>}

\subsubsection{MANual:REF\_MIN}
Only available when the manual control dialog is active.

\query{Queries the minimum observed reference ADC value in the last sampling period}{MANual:REF\_MIN?}{None}{minimum ADC value}

\subsubsection{MANual:REF\_MAX}
Only available when the manual control dialog is active.

\query{Queries the maximum observed reference ADC value in the last sampling period}{MANual:REF\_MAX?}{None}{maximum ADC value}

\subsubsection{MANual:REF\_MAG}
Only available when the manual control dialog is active.

\query{Queries the observerd magnitude at the reference receiver in the last sampling period}{MANual:REF\_MAG?}{None}{port 1 magnitude (linear unit, arbitrary scale)}

\subsubsection{MANual:REF\_PHAse}
Only available when the manual control dialog is active.

\query{Queries the observed phase at the reference receiver in the last sampling period}{MANual:REF\_PHAse?}{None}{phase in degree (random value because it is relativ to an internal sampling clock)}

\section{Streaming data}
The SCPI server works well for configuring the device and also for reading trace data once an acquition is done. But it isn't very well suited for reading data while the device is capturing it. For some applications (e.g. when running continuous sweeps) it may be beneficial to process the data externally as it getting captured. For this purpose, the LibreVNA-GUI supports streaming the data over dedicated ports.

These streaming servers have to be enbled first. This can be done in \menu[,]{Window,Preferences,Streaming Servers}.

There are a total of 5 streaming servers available. They can all be enabled and used at the same time, although not all servers will output data all the time.

\begin{itemize}
\item \textbf{VNA raw data:} Outputs the raw S-parameters without any calibration applied. This output is always available, even when a calibration is enabled or de-embedding it active. Apart from averaging (if enabled) no processing is done on the data.
\item \textbf{VNA calibrated data:} Outputs the calibrated S-parameters with the calibration applied. This output is only available when a calibration is enabled.
\item \textbf{VNA de-embedded data:} Outputs the de-embedded S-parameters with the de-embbeding and calibration (if enabled) applied. This output is only available when de-embedding is active.
\item \textbf{SA raw data:} Outputs the raw (not normalized) power levels from the spectrum analyzer. This output is always available, even when normalizing is active.
\item \textbf{SA normalized data:} Outputs the normalized power levels from the spectrum analyzer. This output is only available when normalizing is active.
\end{itemize}

\vspace{0.5cm}

All servers output a newline-terminated line of json formatted data for each measurement point in the sweep. The format of the output data changes depending on the configured sweep type.

\begin{itemize}
\item VNA frequency or power sweeps:
\begin{example}
{"Z0":50.0,"dBm":-20.0,"frequency":42993000.0,"measurements":{"S11_imag":-0.061379313997181856,"S11_real":0.023033630841401063,"S12_imag":0.3205479840477101,"S12_real":-0.5742283570681822,"S21_imag":-0.3746074656570865,"S21_real":0.6126114195570408,"S22_imag":0.06312766256272641,"S22_real":-0.018668561526968372},"pointNum":7}
\end{example}
\item VNA zero span sweeps:
\begin{example}
{"Z0":50.0,"measurements":{"S11_imag":0.0697879786634009,"S11_real":0.11959939538177566,"S12_imag":-0.2820494760489866,"S12_real":0.4134518710922877,"S21_imag":0.11201366122663228,"S21_real":-0.4258244924547545,"S22_imag":-0.004193267854043776,"S22_real":0.028964823536021114},"pointNum":7,"time":2.438674}
\end{example}
\item Spectrum analyzer non zero span sweeps:
\begin{example}
{"frequency":2182396.0,"measurements":{"PORT1":7.343487141042715e-06,"PORT2":6.78117066854611e-06},"pointNum":445}
\end{example}
\item Spectrum analyzer zero span sweeps:
\begin{example}
{"measurements":{"PORT1":2.595309979369631e-06,"PORT2":1.4385256008608849e-06},"pointNum":7,"time":0.344095}
\end{example}
\end{itemize}

For zero span sweeps, the time in seconds since the beginning of the sweep is given instead of a frequency of power level. The time is always relative to point 0 of the current sweep and point 0 will have a time of 0.

\end{document}

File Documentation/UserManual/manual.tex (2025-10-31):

\documentclass[a4paper,11pt]{article}

\usepackage{titlesec}

\setcounter{secnumdepth}{4}

\titleformat{\paragraph}
{\normalfont\normalsize\bfseries}{\theparagraph}{1em}{}
\titlespacing*{\paragraph}
{0pt}{3.25ex plus 1ex minus .2ex}{1.5ex plus .2ex}

\usepackage[utf8]{inputenc}
\usepackage[T1]{fontenc} % LY1 also works
\usepackage[margin=1in]{geometry}

%% Font settings suggested by fbb documentation.
\usepackage{textcomp} % to get the right copyright, etc.
\usepackage[lining,tabular]{fbb} % so math uses tabular lining figures
\usepackage[scaled=.95,type1]{cabin} % sans serif in style of Gill Sans
\usepackage[varqu,varl]{zi4}% inconsolata typewriter
\useosf % change normal text to use proportional oldstyle figures
%\usetosf would provide tabular oldstyle figures in text

\usepackage{microtype}
\usepackage{siunitx}
\DeclareSIUnit{\belmilliwatt}{Bm}
\DeclareSIUnit{\dBm}{\deci\belmilliwatt}
\sisetup{range-phrase=--, range-units=single, binary-units = true}
\usepackage{graphicx}
\usepackage{tikz}
\usepackage{svg}
%\usepackage{hyperref}
\usetikzlibrary{arrows, shadows}
\tikzset{%
  cascaded/.style = {%
    general shadow = {%
      shadow scale = 1,
      shadow xshift = -1ex,
      shadow yshift = 1ex,
      draw,
      thick,
      fill = white},
    general shadow = {%
      shadow scale = 1,
      shadow xshift = -.5ex,
      shadow yshift = .5ex,
      draw,
      thick,
      fill = white},
    fill = white, 
    draw,
    thick,
    minimum width = 1.5cm,
    minimum height = 2cm}}
    
\usepackage{enumitem}
\setitemize{noitemsep,topsep=0pt,parsep=0pt,partopsep=0pt}
\setenumerate{noitemsep,topsep=0pt,parsep=0pt,partopsep=0pt}
\setlist{leftmargin=*}
\usepackage{listings}
\lstset{
	basicstyle=\ttfamily,
	frame=single,
	breaklines=true,
	morecomment=[l][\color{green}]{\#},
}
\usepackage[os=win]{menukeys}
\renewmenumacro{\keys}[+]{shadowedroundedkeys}

\usepackage{booktabs,caption}
\usepackage[flushleft]{threeparttable}
\newcolumntype{L}[1]{>{\raggedright\let\newline\\\arraybackslash\hspace{0pt}}m{#1}}
\newcolumntype{C}[1]{>{\centering\let\newline\\\arraybackslash\hspace{0pt}}m{#1}}
\newcolumntype{R}[1]{>{\raggedleft\let\newline\\\arraybackslash\hspace{0pt}}m{#1}}
\usepackage{tabularx} 

\usepackage{multirow}

\usepackage{stackengine}
\usepackage{scalerel}
\usepackage{xcolor,mdframed}

\newcommand\danger[1][5ex]{%
  \renewcommand\stacktype{L}%
  \scaleto{\stackon[1.3pt]{\color{red}$\triangle$}{\tiny !}}{#1}%
}

\newenvironment{important}[1][]{%
   \begin{mdframed}[%
      backgroundcolor={red!15}, hidealllines=true,
      skipabove=0.7\baselineskip, skipbelow=0.7\baselineskip,
      splitbottomskip=2pt, splittopskip=4pt, #1]%
   \makebox[0pt]{% ignore the withd of !
      \smash{% ignor the height of !
         %\fontsize{32pt}{32pt}\selectfont% make the ! bigger
         \hspace*{-45pt}% move ! to the left
         \raisebox{-5pt}{% move ! up a little
            {\danger}% type the bold red !
         }%
      }%
   }%
}{\end{mdframed}}

\newcommand\info[1][5ex]{%
  \renewcommand\stacktype{L}%
  \scaleto{\stackon[1.2pt]{\color{blue}$\bigcirc$}{\raisebox{-1.5pt}{\small i}}}{#1}%
}

\newenvironment{information}[1][]{%
   \begin{mdframed}[%
      backgroundcolor={blue!15}, hidealllines=true,
      skipabove=0.7\baselineskip, skipbelow=0.7\baselineskip,
      splitbottomskip=2pt, splittopskip=4pt, #1]%
   \makebox[0pt]{% ignore the withd of !
      \smash{% ignor the height of !
         %\fontsize{32pt}{32pt}\selectfont% make the ! bigger
         \hspace*{-45pt}% move ! to the left
         \raisebox{-5pt}{% move ! up a little
            {\info}% type the bold red !
         }%
      }%
   }%
}{\end{mdframed}}

\usepackage{makecell}
\usepackage{hyperref}
\newcommand{\vna}{LibreVNA}

\newcommand{\screenshot}[2]{\begin{center}

\end{center}}

\title{\vna{} User Manual}
%\author{Jan Käberich (\url{j.kaeberich@gmx.de})}
\begin{document}
\maketitle

%\begin{abstract}
%The Testcard is a platform for the characterization of small energy sources. It is able to charge/discharge up to eight energy sources with a predefined pattern and record their voltages.
%\end{abstract}

\setcounter{tocdepth}{3}
\tableofcontents
\clearpage

%\section*{Nomenclature}
%
%\begin{description}
%\item[Testcard] Board with the hardware to characterize up to eight energy sources.
%\item[CLI] Command Line Interface. Program running on the computer which controls the testcard.
%\item[Channel] One of the eight measurement units on the testcard.
%\begin{description}
%\item[Voltage] Voltage of the energy source connected to the channel.
%\item[Current] Current flowing through the energy source connected to the channel. Defined as the current flowing from the energy source to the testcard, thus the source is discharged for positive and charged for negative values.
%\end{description}
%\item[Load] Application of a current at the channels for a specified timespan.
%\item[Measurement] Single measurement of channel voltages at a specified point in time.
%\item[Trace] Periodic measurement of channel voltages.
%\item[Sequence] A combination of loads, measurements and traces.
%\end{description}

\section{Overview}

\begin{tikzpicture}
\begin{scope}[xshift=1.5cm]
    \node[anchor=south west,inner sep=0] (image) at (0,0) {};
    \begin{scope}[x={(image.south east)},y={(image.north west)}]
		\node [anchor=south, align=center] (port1) at (0,1) {Port 1};
		\node [anchor=south, align=center] (port2) at (0,0.2) {Port 2};
		\node [anchor=west, align=center] (leds) at (1.05,0.8) {LEDs\\ \footnotesize Ready\\ \footnotesize Debug\\ \footnotesize Port1\\ \footnotesize Port2\\ \footnotesize Ext. Reference\\ \footnotesize Source unlocked\\ \footnotesize LO unlocked\\ \footnotesize FPGA unlocked\\ \footnotesize Booting\\ \footnotesize Power};
		\node [anchor=west, align=center] (power) at (1.05,0.5) {External Power \\ \footnotesize (optional)};
		\node [anchor=west, align=center] (usb) at (1.1,0.4) {USB};
		\node [anchor=west, align=center] (refout) at (1.1,0.2) {Reference\\Output};
		\node [anchor=west, align=center] (refin) at (1.1,0) {Reference \\Input};

        \draw [-*, ultra thick, gray] (port1) to[] (0.02,0.89);
        \draw [-*, ultra thick, gray] (port2) to[] (0.02,0.09);
        \draw [-*, ultra thick, gray] (leds) to[] (0.8,0.84);
        \draw [-*, ultra thick, gray] (power) to[] (0.91,0.55);
        \draw [-*, ultra thick, gray] (usb) to[] (0.91,0.5);
        \draw [-*, ultra thick, gray] (refout) to[] (0.97,0.23);
        \draw [-*, ultra thick, gray] (refin) to[] (0.97,0.1);
    \end{scope}
\end{scope}
\end{tikzpicture}%

\subsection{USB}
The \vna{} uses a USB-C connector as the power supply and for data transmission. The hardware supports the USB power delivery standard\footnote{Work in progress, the device will not negotiate USB-PD yet}, requires \SI{5}{\volt} and draws up to \SI{1.2}{\ampere} of current.

The implemented USB device is limited to USB 2.0 Fullspeed and data transmission will work with any USB 2.0 or 3.0 port (no USB-C required). However, the current consumption exceeds the specifications for USB 2.0 and 3.0 ports and the \vna{} may be unable to fully boot when no external power is applied and the USB host limits the current.
\subsection{External Power}
Input jack for external DC power (\SI{5}{\volt}, \SI{1.5}{\ampere}, positive center pin). If a power source is connected, no current is drawn from the USB port anymore.
\subsection{RF ports}
RF connector to connect the DUT. Both ports are identical and the device architecture supports full S-Parameter measurements (S11, S21, S12 and S22).
\begin{important}
The RF ports have no input protection, so do not apply a signal with more than +\SI{10}{\dBm} of power.
\end{important}
\subsection{LEDs}
Ten LEDs indicate the status:
\begin{description}
\item [Ready (green)] Indicates fully booted \vna{}, ready to take measurements
\item [Debug (green)] Not used at the moment
\item [Port 1 (green)] Active output signal on port 1
\item [Port 2 (green)] Active output signal on port 2
\item [Ext. Reference (green)] External reference in use
\item [Source unlocked (red)] The source PLL failed to lock (it may turn on briefly during a sweep, this is not a problem)
\item [LO unlocked (red)] The 1.LO PLL failed to lock (it may turn on briefly during a sweep, this is not a problem)
\item [FPGA unlocked (red)] The FPGA clock PLL failed to lock
\item [Booting (red)] Indicates boot process, also used for error codes
\item [Power (green)] USB power valid
\end{description}
\subsection{Reference Output}
Optional reference output port (user selectable \SI{10}{\mega\hertz} or \SI{100}{\mega\hertz}). The output power is approximately +\SI{3}{\dBm}.
\subsection{Reference Input}
High impedance reference input port. When applying a \SI{10}{\mega\hertz} input signal, it can be used to overwrite the internal TCXO.
\begin{information}
Due to the high impedance input, the external input may detect a valid signal when picking up external radiation. If this is a problem, either terminate the reference input connector or disable automatic reference switching.
\end{information}

\section{Getting started}
\begin{enumerate}
\item Connect the \vna{} to a computer using the USB port. After a couple of seconds, only the "Power" and "Ready" LEDs should stay on. If the "Ready" LED does not turn on or the "Booting" LED indicates an error code, there is a problem and the device will not function properly. See section~\ref{troubleshooting} for possible solutions.
\item Start the PC application to connect to the \vna{}. The window should look similar to this:
\makebox[\textwidth][c]{
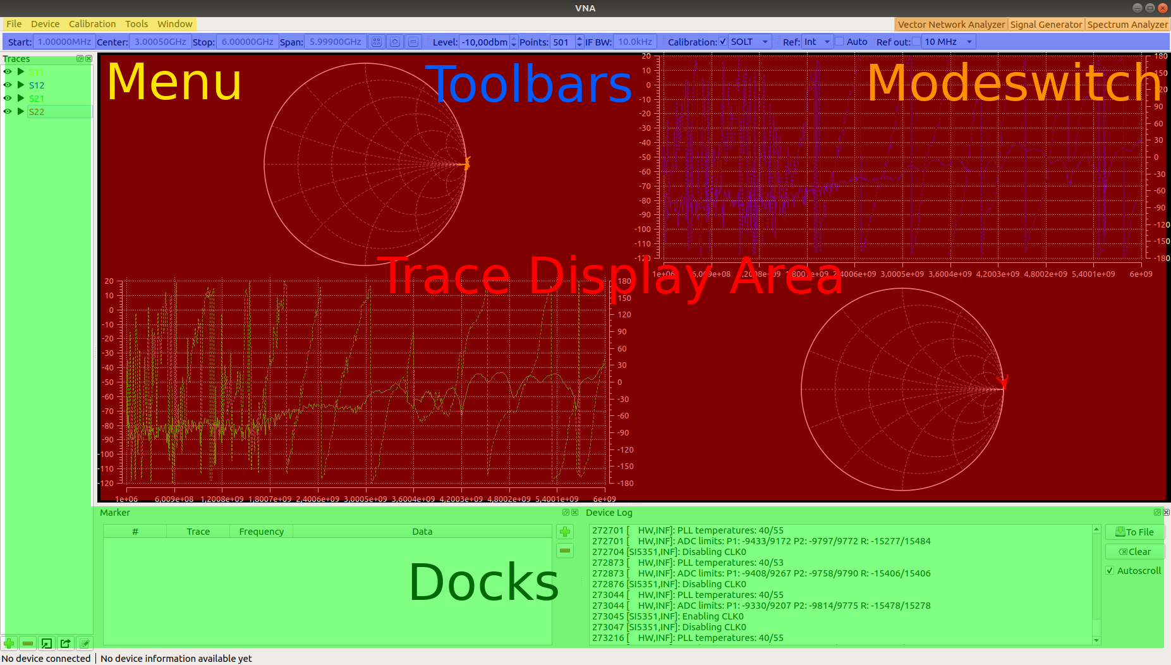
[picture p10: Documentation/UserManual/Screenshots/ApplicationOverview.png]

}
\end{enumerate}
\subsection{GUI element types}
The \vna{} application is made up of six areas containing different types of control:
\begin{itemize}
\item The \textbf{Trace Display Area} shows the measured data in various diagrams.
\item The \textbf{Toolbars} provide access to commonly used device settings. They can be rearranged or disabled (see section~\ref{menu:window}).
\item The \textbf{Menu} at the top left handles less common settings or more complex actions (often with additional popup windows).
\item The \textbf{Docks} mostly provide access to display related settings such as traces and markers. They can be rearranged or disabled (see section~\ref{menu:window}).
\item The \textbf{Statusbar} at the bottom show some basic informations about the connected device. If error conditions (e.g. ADC overload) are present, they are indicated at the bottom right corner.
\item The \textbf{Modeswitch} at the top right allows changing the \vna{} operating mode. Although it is primarily designed as a vector network analyzer, the hardware architecture allow some other operating modes with certain limitations.
\end{itemize}
Depending on the current operating mode, the available toolbars, docks and menu entries change. It is also possible to rearrange the docks and toolbars.

\subsection{Common GUI elements}
Certain control elements are always available, regardless of the selected mode. They control settings of the \vna{} that are not specific to any of the operating modes.

\paragraph{Entering values}\hfill\newline
Most entry fields support SI prefixes. To set a new value, type in the number followed by an SI prefix (e.g. to set \SI{3.2}{\giga\hertz} press \keys{3},\keys{.},\keys{2},\keys{\shift+G}). The accepted prefixes vary depending on the input (e.g. pico is a valid prefix for a capacitance while it will not be accepted for a frequency). 

\subsubsection{Reference Toolbar}
The reference toolbar controls the external reference output as well as the input.
\screenshot{0.5}{ToolbarReference.png}
The reference can be set to "Int" (internal TCXO), "Ext" (external \SI{10}{\mega\hertz} signal) or to automatic mode. In automatic mode, the reference will switch to the external input when a signal is detected, otherwise it will use the internal TCXO.

The external reference output may either be disabled or set to \SI{10}{\mega\hertz} or \SI{100}{\mega\hertz}.

\subsubsection{Device Log Dock}
This dock shows the debug output of the \vna{} (the same messages as on the internal UART port). It may help to identify problems, otherwise it is not required for operation.
\screenshot{1.0}{DockDeviceLog.png}

\subsubsection{File Menu}
Changing the default setup of the application can require a lot of configuration, especially if some of the more complicated math or de-embedding options are used. To simplify this process, setup-files can be saved and opened, which perform these steps automatically. A setup file contains all settings and configuration of these elements:
\begin{itemize}
\item Sweep and Acquisition settings (start/stop frequency, IF bandwidth, ...)
\item The currently active mode (VNA, Signalgenerator or Spectrumanalyzer)
\item Traces (Name, Color, Parameters, ...)
\item Math operations applied to the traces
\item Markers
\item De-embedding options
\item Graph setup and enabled traces
\end{itemize}
\begin{important}
If any part of the setup references another file (i.e. a trace imported from a touchstone file), only the filename is saved. Opening a setup file after moving/deleting any of the referenced files will result in missing data. 
\end{important}

\subsubsection{Device Menu}
The device menu controls the connection state, allows low level hardware access and to perform firmware updates:
\begin{itemize}
\item \textbf{Update Device List:} Scans the USB port for connected devices. Clicking this action simply updates the list of devices, no connection is established.
\item \textbf{Connect to:} Select which \vna{} to connect to. Different devices are identified by their serial number.
\item \textbf{Disconnect:} Disconnect from the \vna{}.
\item \textbf{Manual Control:} Starts the manual control dialog in which all hardware settings are accessible (mostly used for testing purposes):
\screenshot{1.0}{DialogManualControl.png}
\item \textbf{Firmware Update:} Load a new microcontroller firmware and FPGA configuration into the \vna{}. Do not disconnect power while updating the firmware!
\screenshot{0.6}{DialogFirmwareUpdate.png}
\end{itemize}

\subsubsection{Window Menu}
\label{menu:window}
The window menu allows hiding not needed toolbars and docks. It also contains some application preferences.

\section{Vector Network Analyzer}
In this operating mode, the \vna{} takes S-parameter measurements. A source signal is generated and alternately applied to the RF ports. The incoming signal at both RF ports is measured, resulting in the four S-parameters S11 and S21 (when the source signal is routed to port 1) as well as S12 and S22 (when it is routed to port 2).

\subsection{Signal processing architecture}
\label{vna:dsp}
This section contains some details of the signal flow inside the \vna{}-Application. Knowledge of the signal flow is not required to operate the \vna{} but may help to understand certain features and limitations.
\tikzstyle{block} = [draw, rectangle, 
    minimum height=3em, minimum width=6em]
\tikzstyle{sum} = [draw, fill=blue!20, circle, node distance=1cm]
\tikzstyle{input} = [coordinate]
\tikzstyle{output} = [coordinate]
\tikzstyle{pinstyle} = [pin edge={to-,thin,black}]
\tikzset{%
  cascaded/.style = {%
    general shadow = {%
      shadow scale = 1,
      shadow xshift = -1ex,
      shadow yshift = 1ex,
      draw,
      %thick,
      fill = white,
      },
    general shadow = {%
      shadow scale = 1,
      shadow xshift = -.5ex,
      shadow yshift = .5ex,
      draw,
      %thick,
      fill = white,
      },
    fill = white, 
    draw,
    %thick,
    %minimum width = 1.5cm,
    %minimum height = 2.1cm
    }}

% The block diagram code is probably more verbose than necessary
\begin{center}
\begin{tikzpicture}[auto, node distance=2cm,>=latex']
    % We start by placing the blocks
	\node [block] (VNA) {VNA Hardware};
	\node [block, below of=VNA] (cal) {Calibration};
	\node [block, below of=cal] (deemb)  {De-embedding};
	\node [cascaded, block, below of=deemb, align=center, node distance=3cm, minimum height=2cm] (traces)  {Traces\\ \\ \\};
	\node [block, dashed, minimum width=4em, minimum height=2em, below of=traces, node distance=0.2cm] (math) {Math};
	\node [cascaded, block, node distance=3cm, below of=traces] (graphs)  {Graphs};

	\draw [->] (VNA) -- node {uncalibrated S parameter set (S11,S12,S21,S22) over USB} (cal);
	\draw [->] (cal) -- node {calibrated S parameter set (S11,S12,S21,S22)} (deemb);
	\draw [->] (deemb) -- node {individual S parameters} ([yshift=1ex]traces.north);
	\node [left of=traces, node distance=4cm](import){};
	\draw [->] (import) -- node {imported files} ([xshift=-1ex]traces.west);
	\node [right of=traces, node distance=6cm](export){};
	\draw [->] (traces.east) -- node {CSV/Touchstone export} (export);
	\draw [->] (traces) -- node {complex frequency/time domain data} ([yshift=1ex]graphs.north);
\end{tikzpicture}
\end{center}

The central element of the signal flow is the concept of \textbf{traces}. A trace is created from a single S parameter across frequency (either measured by the \vna{} or imported from an external file). Once the data is captured in a trace, optional math operations may be applied to it (e.g. performing a TDR to transform the data into the time domain) and the result of these operations are passed on to the graphs.

When capturing data from the \vna{}, additional operations take place before the data is fed to the traces. First, the \vna{} measures the four S parameters between its two ports. The raw measurements are transferred through USB. The first processing block is the calibration (see also section~\ref{vna:calibration}), followed by optional de-embedding procedures. After the de-embedding, the four S parameters are split into individual S parameters and the relevant traces are updated.

This concept has several consequences when using the \vna{}, some of which are:
\begin{itemize}
\item You can always take calibration measurements. No matter how the de-embedding or math operations in the traces are set up, they will never influence the calibration routine
\item A valid calibration is required before using de-embedding options (otherwise, most de-embedding options won't be able to work properly)
\item Applying a calibration or de-embedding to traces imported from files is not possible
\item Once the data arrives in the traces, the S parameters are no longer associated (e.g. there is no connection between S11 and S21 anymore. It is possible to "pause" the trace capturing S11 while S21 continues to get updated)
\end{itemize}

\subsection{Sweep Toolbar}
This toolbar sets the swept frequency range.
\screenshot{1.0}{ToolbarSweep.png}
The start/stop and center frequency as well as the span can be set directly.

Additionally, the sweep toolbar contains buttons for zooming in/out around the center frequency and a preset to set the sweep to the full frequency range.
\subsection{Acquisition Toolbar}
\screenshot{0.7}{ToolbarVNAAcquisition.png}
\begin{itemize}
\item \textbf{Level:} The amount of power used for stimulus generation. The dynamic range decreases when using smaller values. It is recommended to use the highest available settings when measuring passive networks. When measuring active devices (e.g. amplifiers), decrease the stimulus power in such a way that the input power into any port does not rise above \SI{-10}{\dBm} to stay within the linear range of the \vna.
\item \textbf{Points:} Amount of measurement points in one sweep. More points provide finer frequency resolution but also increase sweep time.
\item \textbf{IF BW:} Bandwidth of final IF measurement. Low bandwidths increase the sweep time but improve the noisefloor. At higher frequencies (roughly above \SI{3}{\giga\hertz}), the dynamic range is limited by the isolation between the ports and decreasing the IF bandwidth does not improve the noisefloor anymore.
\item \textbf{Averaging:} Moving average across multiple sweeps.
\end{itemize}

\subsection{Traces}
Adding/configuring traces is handled by the \textbf{Trace Dock} (by default on the left side): 
\screenshot{0.3}{TraceDock.png}
The list shows all available traces, by default the four S parameters S11, S12, S21 and S22. Different icons in front of the trace names indicate the state of the trace. Clicking on one of the icons toggles the state:
\begin{itemize}
\item \includesvg[height=8pt]{Screenshots/visible}/\includesvg[height=10pt]{Screenshots/invisible}: Enable/disable global visibility: Shows/hides the trace an all graphs it is enabled on.
\item \includesvg[height=8pt]{Screenshots/play}/\includesvg[height=8pt]{Screenshots/pause}: Play/pause. Only available when the trace is fed from live VNA data, not when it was created from a touchstone file. Pausing a trace freezes the current data, new measurements from the \vna{} will not update the trace.
\item \includesvg[height=8pt]{Screenshots/math_enabled}/\includesvg[height=10pt]{Screenshots/math_disabled}: Enable/disable math. Only available if at least one math operation is present.
\end{itemize}
\noindent
Creating a new trace or double clicking on an existing trace opens the "edit trace" window:
\screenshot{1.0}{TraceEdit.png}
On the left side, additional trace parameters can be changed, while the right side of the window handles math operations that will be applied to the trace data. The available trace parameters are:
\begin{itemize}
\item \textbf{Name}
\item \textbf{Color}
\item \textbf{Velocity factor} (only relevant when transforming into the time domain)
\item \textbf{Data source} (Live Capture/From File/From Math)
\end{itemize}

\subsubsection{Trace Data Sources}
Every trace can receive its data from one of three source:
\begin{itemize}
\item \textbf{Live Capture:} Sampled data from the LibreVNA are added to the trace in real time
\item \textbf{From File:} Import static data from an external touchstone or CSV file
\item \textbf{From Math:} Combine data from other traces with math operations to create a new trace
\end{itemize}

\paragraph{Live Capture}
\screenshot{0.5}{LiveCapture.png}
The trace is constantly updated by the data received from a connected and sweeping LibreVNA. The available Live Capture parameters are:
\begin{itemize}
\item \textbf{Type:} Live Captures can be 3 different types:
\begin{itemize}
\item \textbf{Overwrite:} The trace data is overwritten each sweep
\item \textbf{Max hold:} The trace data with the highest signal magnitude is persisted
\item \textbf{Min hold:} The trace data with the lowest signal magnitude is persisted
\end{itemize}
\item \textbf{Parameter:} The S-Parameter you want traced
\end{itemize}

\paragraph{From File}
\screenshot{0.5}{FromFile.png}
The trace data is extracted from a specified file. If the file contains data for multiple traces, the correct parameter must be specified as well.
\begin{important}
When saving a setup with traces created from files, the actual trace data is not saved. Instead, the path to the source file is added to the setup file. Opening the created setup file will result in empty traces if the original source file is no longer present.
\end{important}

\paragraph{From Math}
\label{trace:fromMath}
\begin{information}
This section is about creating a trace based on data from other traces and combining them with math operations. If you are looking to change or transform the trace data itself without using any data from other traces, see section~\ref{trace:math}.
\end{information}
\screenshot{0.5}{FromMath.png}
The trace is created from other traces and user-defined math operations. To create a trace from math, perform the following steps:
\begin{enumerate}
\item Select "From Math" as the trace source
\item Check all traces on which the trace should depend. Not all traces can be used, there are the following limitations:
\begin{itemize}
\item All used traces must have the same output domain
\item There can be no circular dependencies between "From Math" traces
\end{itemize}
\item (Optional) Change the variable name for the selected traces
\item Enter the formula using the chosen variables
\end{enumerate}

\subsubsection{Math operations}
\label{trace:math}
\begin{information}
This section is about transforming the already acquired trace data. If you are looking to create a trace by combining data from other traces and math operations, see section~\ref{trace:fromMath}.
\end{information}
The "math operations" section on the right contains the additional calculations that are performed on the trace data before it is displayed. Initially, it contains only one line (representing the measured data). New operations can be created using the buttons on the right. Each math operation adds a new line to the list, consisting of three columns:
\begin{itemize}
\item \textbf{Status:} Visual indication whether the calculation succeeded. On warnings or errors, a mouse-over text gives a hint about the problem.
\item \textbf{Description:} Short description of the configured math operation. Double clicking will open an (operation dependent) editing dialog providing more details.
\item \textbf{Output Domain:} Domain (Time or Frequency) of the data after this math operation. Certain math operations can only be applied to time domain data, others only to frequency domain data. The output domain at the last line decides in which domain the trace is displayed on the graphs.
\end{itemize}
Populated with several math operations, the window could look like this:
\screenshot{1.0}{TraceMath.png}
In this example, time domain gating is performed:
\begin{itemize}
\item A median filter is applied to the data, smoothing the trace a little bit (not actually necessary for the time domain gating)
\item Next, a TDR transformation creates the time domain response of the measurement
\item The impulse response is truncated at and above \SI{1}{\meter} with a custom expression
\item At last the time domain response is transformed back into the frequency domain with a DFT
\end{itemize}

\paragraph{Median Filter}
\screenshot{0.4}{MathOpMedianFilter.png}
The median filter filters values across frequency (or power or time, depending on acquisition settings and previous math operations). For every point in a trace it takes the point and several surrounding points, sorts them and uses the middle point of the sorted list as the filtered value. It is a great option to get rid of fixed spikes (e.g. due to LO feedthrough or unwanted external signals). In comparison, the averaging function from the toolbar will smooth captured traces over time but is not able to remove static spikes.

Adjustable settings:
\begin{itemize}
\item \textbf{Kernel size:} Number of sample points that are used for the sorted list
\item \textbf{Sorting method:} As most input values are complex, there are different options to sort the values:
\begin{itemize}
\item Absolute Value
\item Phase
\item Real part
\item Imaginary part
\end{itemize}
\end{itemize}
\paragraph{TDR}
\screenshot{0.4}{MathOpTDR.png}
The TDR takes frequency domain data and transforms it into time domain data. The number of output samples as well as the time span is determined by the number of input samples and the selected frequency span.

Adjustable settings:
\begin{itemize}
\item \textbf{Mode:} A TDR can be performed in two different modes:
\begin{itemize}
\item \textbf{Lowpass:} Input samples should start at near DC, i.e. the start frequency must be small compared to the span. A step response can be calculated as the DC point can be extrapolated.
\item \textbf{Bandpass:} Input samples may use any frequency and span. Only an impulse response can be calculated as the DC point is unknown.
\end{itemize}
\item \textbf{Compute Step Response:} Enable calculation of step response as well (only available in lowpass mode)
\item \textbf{DC point:} Choose between extrapolating the DC point from frequency data or specifying it manually (only available in lowpass mode)
\item \textbf{Window:} A window is applied before performing the transformation. Available windows are:
\begin{itemize}
\item Rectangular
\item Gaussion
\item Hann
\item Hamming
\item Blackman
\end{itemize}
\end{itemize}
\paragraph{DFT}
\screenshot{0.4}{MathOpDFT.png}
The DFT is the inverse operation to the TDR and is used to transform time domain data back into the frequency domain.

Adjustable settings:
\begin{itemize}
\item \textbf{DC frequency:} Depending on the original source data of the input time domain data, it may have been calculated from a frequency range that does not start at DC. Transforming the time domain data back into the frequency domain will result in frequency data at and around DC. This setting allows to move the transformed frequency data to the correct frequency.
\begin{itemize}
\item \textbf{Automatic:} The DC frequency is determined automatically by looking at the last TDR operation that resulted in the time domain data and extracting the correct frequency from that. Usually, this results in the correct frequencies.
\item \textbf{Automatic:} If for any reason a different frequency range must be used, the actual frequency of the DC bin can be specified manually.
\end{itemize}
\item \textbf{Window:} A window is applied before performing the transformation. Available windows are:
\begin{itemize}
\item Rectangular
\item Gaussion
\item Hann
\item Hamming
\item Blackman
\end{itemize}
\end{itemize}
\paragraph{Custom Expression}
\screenshot{1.0}{MathOpCustomExpression.png}
The custom expression allows user-specific calculations on the trace data. It can only use a single data point as the input value. Access to other data points (e.g. at a lower/higher frequency or from an earlier sweep) is not possible. Custom expressions can work with input data of any domain and result in output data of the same domain. Depending on the input data domain, different variables are available and shown in the dialog.

If the expression contains syntax errors, check the mouse-over text in the status column of the trace edit dialog.
\paragraph{Time Gate}
\screenshot{1.0}{MathOpTimeGate.png}
The time gate allows filtering data in the time domain. It can either be used as a bandpass (only passing time domain data within a specified window) or as a bandstop (blocking time domain data in a specified window). The displayed graph allows for easier adjustments. The green trace is the time domain input data and is updated live. The red line is the currently selected gate filter.

The gate filter can be adjusted by manually specifying the start/stop or center/span times. As an alternative, the filter edges can also be moved on the graph with the mouse.
Adjustable settings:
\begin{itemize}
\item \textbf{Window:} The window function influences the filters pass- and stopband. The filter is constructed by first calculating the ideal filter coefficients in the frequency domain. Afterward, the coefficients are windowed to limit spectral leakage and finally transformed into the time domain (which is displayed in the graph).
\begin{itemize}
\item Rectangular
\item Gaussion
\item Hann
\item Hamming
\item Blackman
\end{itemize}
\end{itemize}

\subsection{Calibration}
\label{vna:calibration}
This section is about the VNA calibration which is used to remove the effect of connectors and cables (as well as imperfections from the \vna{} itself). For the amplitude calibration see section~\ref{amplitude:calibration}.

Some general knowledge about the different calibration types is assumed, this manual only explains how to use them with the \vna{}.
\subsubsection{Introduction}
This section contains some implementation details of the calibration. It can be skipped but understanding them can be helpful when using the calibration.

Section~\ref{vna:calibration} uses the following definitions:
\begin{itemize}
\item \textbf{Calibration standard:} A single calibration standard (e.g. an Open standard). Most standards can either be defined by coefficients or a measurement file.
\item \textbf{Calibration kit:} It contains the definition of the calibration standards. When the calibration error terms are calculated, these definitions are taken into account.
\item \textbf{Measurement:} Raw (uncorrected) measurement of a calibration standard. Depending on the type of desired calibration, different measurements are required.
\item \textbf{Calibration type:} The calibration type determines which errors are corrected by the calibration and how the error terms are derived from the measurements.

The calibration type is followed by the ports for which the calibration corrects errors. For example, when using a SOLT calibration on ports 1 and 2, the calibration type will be shown as "SOLT\_12".
\end{itemize}

For the most accurate results, the calibration should be performed with the same settings (span, number of points, stimulus level, ...) as the intended measurement. However, it is possible to change these settings after the calibration. The calibration will be interpolated when a different span is used.

\subsubsection{Types}
Several different calibration types are available:
\begin{center}
\begin{threeparttable}
\begin{tabularx}{\textwidth}{L{2cm}|X|L{6cm}}
    \toprule
    \textbf{Type} & \textbf{Applied corrections} & \makecell{\textbf{Required}\\ \textbf{measurements}}\\
    \hline
      SOLT   	&   Full SOLT calibration, removes influences at all ports and also corrects transmission measurements & \makecell{Open and Short for each port\\Load or SlidingLoad for each port\\Through between all of ports\\ Isolation(optional)}\\ 
    \hline
      ThroughNormalization   &  Only corrects for losses and phaseshift in through measurements. While this is not as accurate as SOLT, it is useful e.g. when measuring only the frequency response of a filter because it requires far less calibration measurements.  & \makecell{Through between all of ports}\\ 
    \hline
      TRL   	&   Full two-port calibration but with different (less accurately defined) standards than SOLT & \makecell{Reflection for each port\\Through between all of ports\\Line between all of ports}\\ 
      \bottomrule
\end{tabularx}
\end{threeparttable}
\end{center}

\subsubsection{Calibration Kit}
The calibration kit contains the calibration standard definitions used in the calibration. It can be edited through the menu: \menu[,]{Calibration,Edit Calibration Kit} The same dialog can also be reached through the calibration measurement dialog: \menu[,]{Calibration,Calibration Measurements,Edit Calibration Kit} 

The calibration kit can consist of an arbitrary number of calibration standards.
\screenshot{0.5}{CalibrationKitDialog.png}

The three text fields (Manufacturer, Serial number and Description) are meant for easy identification of the correct calibration kit. None of the contents are used anywhere by the GUI and the user is free to enter any text.

Calibration standards can be added, deleted and sorted with the buttons to the right of the calibration standard list. Double-click a standard to edit its definition.

\paragraph{Open Standard}
\screenshot{0.5}{OpenStandardDialog.png}
The Open standard can either be defined by its coefficients or by a touchstone measurement file. If defined by a touchstone file, the file limits the span of the calibration for which the standard can be used.

\textbf{Coefficients:}
\begin{itemize}
\item \textbf{Z0:} Impedance of the transmission line from the reference plane to the open termination
\item \textbf{Offset delay:} One-way length of the transmission line
\item \textbf{Offset loss:} Loss/attenuation of the transmission line
\item \textbf{C0--C3:} Parasitic capacitance of the open termination
\end{itemize}

\paragraph{Short Standard}
\screenshot{0.5}{ShortStandardDialog.png}
The Short standard can either be defined by its coefficients or by a touchstone measurement file. If defined by a touchstone file, the file limits the span of the calibration for which the standard can be used.

\textbf{Coefficients:}
\begin{itemize}
\item \textbf{Z0:} Impedance of the transmission line from the reference plane to the short termination
\item \textbf{Offset delay:} One-way length of the transmission line
\item \textbf{Offset loss:} Loss/attenuation of the transmission line
\item \textbf{L0--L3:} Parasitic inductance of the short termination
\end{itemize}

\paragraph{Load Standard}
\screenshot{0.5}{LoadStandardDialog.png}
The Load standard can either be defined by its coefficients or by a touchstone measurement file. If defined by a touchstone file, the file limits the span of the calibration for which the standard can be used.

\textbf{Coefficients:}
\begin{itemize}
\item \textbf{Resistance:} Resistance of the termination resistor
\item \textbf{Z0:} Impedance of the transmission line from the reference plane to the termination resistor
\item \textbf{Offset delay:} One-way length of the transmission line
\item \textbf{Offset loss:} Loss/attenuation of the transmission line
\item \textbf{Parallel C:} Parasitic capacitance in parallel to the termination resistor
\item \textbf{Series L:} Parasitic inductance in series to the termination resistor
\item \textbf{Load Parameter Model:} Two different Load models are implemented, with the order of the parasitic elements swapped:
\begin{itemize}
\item Series L first: \screenshot{0.8}{Lfirst.pdf}
\item Shunt C first: \screenshot{0.6}{Cfirst.pdf}
\end{itemize}
\end{itemize}

\paragraph{Reflect Standard}
\screenshot{0.5}{ReflectStandardDialog.png}
The Reflect standard doesn't have any coefficients as it is an unknown standard. The only available choice is whether it is assumed to be a short or an open.

\paragraph{Through Standard}
\screenshot{0.5}{ThroughStandardDialog.png}
The Through standard can either be defined by its coefficients or by a touchstone measurement file. If defined by a touchstone file, the file limits the span of the calibration for which the standard can be used.

\textbf{Coefficients:}
\begin{itemize}
\item \textbf{Z0:} Characterisitc impedance of the Through standard (fixed to \SI{50}{\ohm} for now)
\item \textbf{Delay:} One-way length of the transmission line
\item \textbf{Loss:} Loss/attenuation of the transmission line
\end{itemize}

\paragraph{Line Standard}
\screenshot{0.5}{LineStandardDialog.png}
The Line standard is an unknown standard and is not accurately defined by coefficients. The only parameter is its delay to determine the usable span when using this standard in a TLR calibration. The delay mustn't be specified with high accuracy either.

\subsubsection{Measurements}
\label{vna:cal:meas}
The calibration measurements can be found in \menu[,]{Calibration,Calibration Measurements}. Initially, the list is empty. Measurements can be added and removed with the buttons on the right of the list. For convenience, the required measurements for common calibrations can also be created automatically (select the desired calibration type from the drop-down list on the top).

\screenshot{1.0}{CalibrationMeasurements.png}

Each measurement has a few settings, depending on the measurement type:

\paragraph{Open Measurement}
\screenshot{1.0}{OpenMeasurement.png}
\begin{itemize}
\item Select the calibration standard to be used with this measurement.
\item Select the port
\end{itemize}

\paragraph{Short Measurement}
\screenshot{1.0}{ShortMeasurement.png}
\begin{itemize}
\item Select the calibration standard to be used with this measurement.
\item Select the port
\end{itemize}

\paragraph{Load Measurement}
\screenshot{1.0}{LoadMeasurement.png}
\begin{itemize}
\item Select the calibration standard to be used with this measurement.
\item Select the port
\end{itemize}

\paragraph{Sliding Load Measurement}
\screenshot{1.0}{SlidingLoadMeasurement.png}
\begin{itemize}
\item No calibration standard is required
\item Select the port
\item At least three Sliding Load measurements must be used per port, each with a different setting on the sliding load. More measurements may result in more accurate results and there is no upper limit on measurements
\end{itemize}

\paragraph{Reflect Measurement}
\screenshot{1.0}{ReflectMeasurement.png}
\begin{itemize}
\item Any open, short or reflect standard can be selected
\item Select the port
\end{itemize}

\paragraph{Through Measurement}
\screenshot{1.0}{ThroughMeasurement.png}
\begin{itemize}
\item Select the calibration standard
\item Select the ports
\item When the Through standard is definded by a touchstone file and the port order in that file does not match the port order in the measurement, check the "Reversed" checkbox. Through standards defined by coefficients are always symmetrical and the checkbox has no effect
\end{itemize}

\paragraph{Line Measurement}
\screenshot{1.0}{LineMeasurement.png}
\begin{itemize}
\item Select the calibration standard
\item Select the ports
\item As Line standards are always symmetrical, the checkbox has no effect
\end{itemize}

\paragraph{Isolation Measurement}
\screenshot{1.0}{IsolationMeasurement.png}
\begin{itemize}
\item No settings available
\end{itemize}

\paragraph{Taking measurements}
To take a measurement, select the corresponding measurement and press \keys{Measure}. Multiple measurements may be taken at the same time if they use different ports.
\begin{information}
All measurements required by a calibration type should have the same start and stop frequencies as well as number of points. Do not change the span between measurements.
\end{information}

\subsubsection{Enabling a calibration}
After all required measurements have been taken, the calibration can be enabled. There are two different options available for this:
\begin{itemize}
\item Select the calibration type in the calibration toolbar and enable the checkbox. If all required measurements have already been taken, the calibration is activated immediately. If some measurements are missing or have been taken with different span settings, applying the calibration is not possible. In that case, the calibration measurement dialog (see section~\ref{vna:cal:meas}) opens instead.
\item Select the calibration type in the calibration measurement dialog and click "Activate". Only calibration types for which all required measurements are available can be activated.
\end{itemize}

%\paragraph{Example:} After starting the application, the following steps are necessary to perform a SOLT calibration.
%\begin{enumerate}
%\item Edit the calibration kit to match the standards used in the measurements or open a saved calibration kit file.
%\item Change the span and acquisition settings to match the intended measurement. At this point no calibration is active yet, the measured data (here with both port directly connected) is inaccurate:
%\screenshot{1.0}{VNAUncalibratedThrough.png}
%\item Select \menu[,]{Calibration,Calibration Measurements} and take the required measurements. In this case, the measurement "Isolation" (optional for SOLT) has not been taken, as well as the "Line" measurement (not required for SOLT)
%\screenshot{1.0}{CalibrationMeasurementsSOLT.png}
%\item Close the "Calibration Measurements" window and activate the SOLT calibration by selecting \menu[,]{Calibration,SOLT}:
%\screenshot{0.3}{MenuActivateSOLT.png}
%Alternatively, the calibration can be activated by choosing "SOLT" in the toolbar and enabling the calibration checkbox:
%\screenshot{0.3}{ToolbarActivateSOLT.png}
%\item The calibration is active and connecting both ports directly results in a corrected measurement:
%\screenshot{1.0}{VNACalibratedThrough.png}
%\end{enumerate}

\subsubsection{Saving/Loading}
Once a calibration is active, it can be saved by selecting \menu[,]{Calibration,Save}. All raw measurements are saved together with the calibration type and the calibration kit.

Similarly, a saved calibration can be opened by selecting \menu[,]{Calibration,Load}. It is applied immediately after opening.

\subsubsection{Assigning a default calibration to a device}
Once a calibration has been saved, it can be selected as the default calibration for a specific device. To do so, first connect to the device and then select \menu[,]{Device,Default Calibration,Assign...}. Once a default calibration has been assigned, it will automatically be opened and applied every time the application connects to that specific device.

\subsubsection{Viewing error terms/calibration measurements}
The error terms calculated from the calibration measurements as well as the raw measurements used to derive these error terms can be imported by selecting \menu[,]{Calibration,Import error terms as traces} or \menu[,]{Calibration,Import measurements as traces}. This feature is mostly intended to debug calibration problems and is not normally required.

\subsubsection{Electronic Calibration}
Performing a calibration, especially when multiple ports are used, can require a lot of manual steps. The \vna{} supports an automatic electronic calibration, which takes all the required measurements for a SOLT calibration on its own. To use the electronic calibration, the LibreCAL\footnote{\url{https://github.com/jankae/LibreCAL}} device is required.

To start the electronic calibration, select \menu[,]{Calibration,Electronic Calibration} or \menu[,]{Calibration,Calibration Measurements,Electronic Calibration}. There is no need to create a calibration kit first, as the electronic calibration will use the calibration coefficients stored in the LibreCAL.
\begin{important}
The electronic calibration will delete and replace any currently active calibration and calibration kit. Please store any unsaved calibration data before starting the electronic calibration.
\end{important}

\screenshot{0.6}{eCal.png}

Steps required to perform the electronic calibration:
\begin{enumerate}
\item Connect the LibreCAL via USB to the same machine on which the \vna{}-GUI is running
\item Connect every port of the \vna{} that should be calibrated to one of the ports on the LibreCAL
\item Start the electronic calibration dialog
\item Select the correct LibreCAL device and the coefficients:
\begin{itemize}
\item \textbf{Device:} The serial number of the LibreCAL. Usually, only one should be connected and the serial number will be automatically selected when the dialog is first opened
\item \textbf{Coefficients:} Select the coefficient set to be used. The LibreCAL can store multiple sets of coefficients. Refer to the LibreCAL manual\footnote{\url{https://github.com/jankae/LibreCAL/blob/main/Documentation/manual.pdf}} for detailed information on coefficient sets.
\end{itemize}
\item Check and adjust the port assignments. Ports between the \vna{} and LibreCAL can be connected in any order. Match the ports in the dialog to your physical setup.
\item Press the "Start" button. This will perform the following steps:
\begin{itemize}
\item Fill the calibration kit based on the coefficients extracted from the LibreCAL
\item Take an open, short and load measurement for every port of the \vna{}
\item Take a through measurement for any combination of ports
\item Apply the SOLT calibration. For the FACTORY coefficient set, the reference plane will be at the ports of the LibreCAL
\end{itemize}
\end{enumerate}

\subsection{De-embedding}
The de-embedding options are available under \menu[,]{Tools,De-embedding}. The GUI works similar to the math operations for traces (see section~\ref{trace:math}) but the de-embedding is performed before the data reaches the traces (compare with section~\ref{vna:dsp}).
\screenshot{0.8}{Deembedding.png}

Just like with the math operations, a list shows the de-embedding options. Once a new option is added (or is double clicked) a window opens which allows to configure the option. Depending on the de-embedding option, there might be some user adjustable parameters (e.g. the length and attenuation of a port extension) or the option needs a measurement from the \vna{} to calculate the de-embedding parameters (e.g. take a measurement to automatically measure the port extension length). If a measurement is required at any point, a new window opens with two choices to provide the measurement data:
\screenshot{0.9}{DeembeddingMeas.png}
The first possibility is to click the measure button (with the \vna{} connected) which starts a new measurement. The \vna{} connections must have been setup properly before (e.g. in the case of the port extension: extension cable connected and terminated either into an open or short. The exact setup depends on the de-embedding option). The other possibilty is to provide the measurement by using traces. This is useful if the same measurement has already been taken but the physical setup has changed since then. Select the correct traces for all required S parameters and click the "OK" button.

\subsubsection{Port Extension}
\screenshot{0.4}{DeembeddingPortExtension.png}
The port extension allows moving the reference plane relative to the plane used during the calibration. The port extension is defined by two characteristics:
\begin{itemize}
\item \textbf{Distance/Time:} The one-way distance or time the reference plane will be moved. Setting either parameter will automatically calculate the other by using the velocity factor.
\item \textbf{Loss:} The additional loss introduced by the physical component that caused the reference plane to move. It is further split into two parameters:
\begin{itemize}
\item \textbf{at DC:} One-way loss at \SI{0}{\hertz}
\item \textbf{at a specific frequency:} One-way loss at a chosen frequency, typically higher than the DC loss
\end{itemize}
\end{itemize}

All these parameters can also be calculated automatically by measuring the port extension with either an open or short connected instead of the DUT.

If a port extension is required at multiple ports, add this option once for each port.

\subsubsection{Two Thru}
\screenshot{1.0}{DeembeddingTwoThru.png}
The two thru option is an advanced de-embedding option for when there are additional fixtures between the reference plane and the DUT that can't be easily calibrated out by either a SOLT calibration or a port extension. The are a few prerequisites for using this option:
\begin{itemize}
\item The \vna{} must be calibrated at a reference place which does not include the fixtures
\item The fixtures (everything between the reference plane and the DUT) must be identical for both ports
\item It must be possible to connect the fixtures directly to each other as well as directly to the DUT
\end{itemize}
\vspace{0.5cm}
To create a two thru de-embedding, perform the following steps:
\begin{enumerate}
\item Select the two ports for which the de-embedding will be applied in the configuration section of the dialog
\item Connect both fixtures directly to each other (without the DUT)
\item Take the mandatory 2xThru measurement
\item If the fixtures have a different characteristic impedance than \SI{50}{\ohm}:
\begin{itemize}
\item Insert the DUT between the fixtures
\item Take the optional Fixture-DUT-Fixture measurement
\end{itemize}
\item Compensate the effect of the fixtures by clicking the "Calculate" button in the dialog
\end{enumerate}

\subsubsection{Matching Network}
\screenshot{1.0}{DeembeddingMatchingNetwork.png}
The matching network allows the user to (de-)embed lumped components and arbitrary transmission lines between the DUT and a measurement port.

Available components are:
\begin{itemize}
\item \textbf{Series R/L/C:} Lumped component in series between the port and the DUT
\item \textbf{Parallel R/L/C:} Lumped component from the signal path to GND
\item \textbf{Defined Through:} Any two-port network as defined by a touchstone file
\end{itemize}
Any combination of these components can be dragged into the signal path between the port of the\vna{} and the DUT.

Further settings:
\begin{itemize}
\item \textbf{Operation:} Choose between embedding and de-embedding
\item \textbf{Port:} Port of the \vna{}
\end{itemize}
If a matching network is required at multiple ports, add this option once for each port.

\subsubsection{Impedance Renormalization}
\screenshot{0.4}{DeembeddingImpedanceRenormalization.png}
The \vna{} is a \SI{50}{\ohm} system. S parameter measurements are reported with a \SI{50}{\ohm} reference impedance. With the impedance renormalization, the acquired data can be transformed into what it would look like if the system would have a different reference impedance (e.g. \SI{75}{\ohm}). This transformation influences all traces captured by the \vna{}.
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

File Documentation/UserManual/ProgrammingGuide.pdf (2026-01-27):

## LibreVNA SCPI Programming Guide

January 27, 2026

## Contents

1 Introduction | 7
2 SCPI Server Configuration | 7
3 General Syntax | 7
4 Commands | 8

5 Custom Driver Commands | 63

6 Streaming data | 75

## 1 Introduction

The LibreVNA-GUI contains a TCP server that can be used to control the LibreVNA with SCPI commands.

## 2 SCPI Server Configuration

The server is configurable in the preferences: Window | Preferences | General

If enabled, it will accept any TCP connection at the configured port. Once the connection is established, it can be used to send SCPI commands and receive replies. Only one connection at a time is possible, if a second connection is created, the first one will be closed by the LibreVNA-GUI. Alternatively, a port can be manually configured by setting the “port” argument:

./ LibreVNA - GUI -- port 1234
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

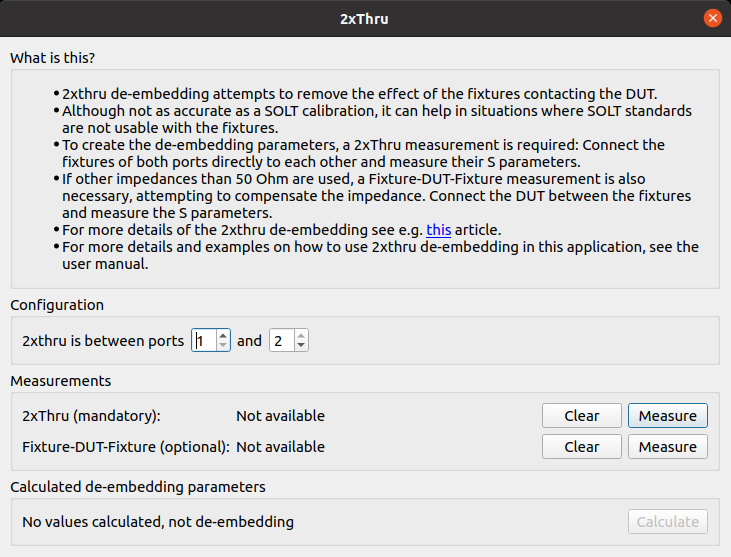
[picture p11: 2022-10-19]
Documentation/UserManual/Screenshots/DeembeddingTwoThru.png

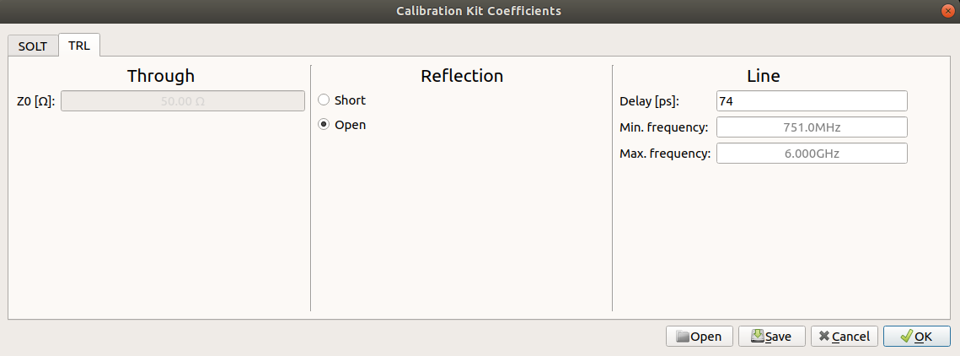
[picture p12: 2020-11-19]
Documentation/UserManual/Screenshots/CalKitTRL.png

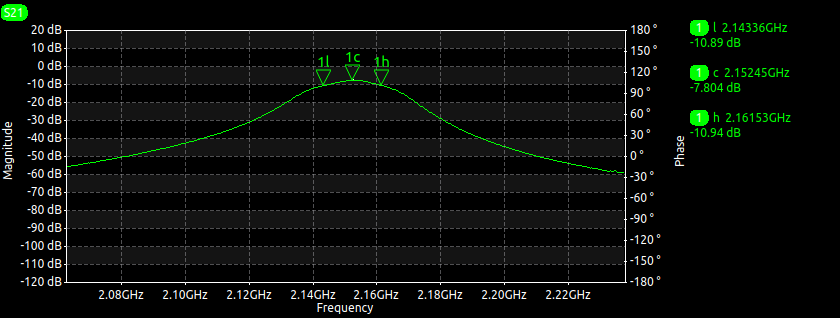
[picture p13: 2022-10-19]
Documentation/UserManual/Screenshots/MarkerBandpassGraph.png

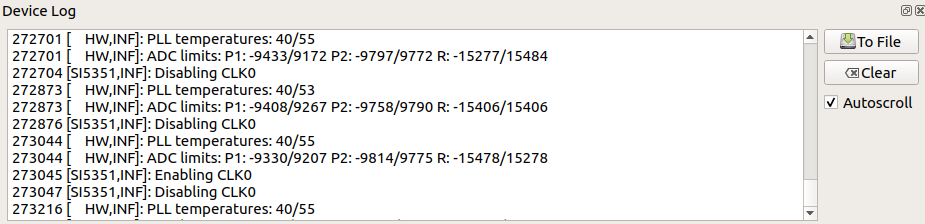
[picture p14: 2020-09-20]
Documentation/UserManual/Screenshots/DockDeviceLog.png

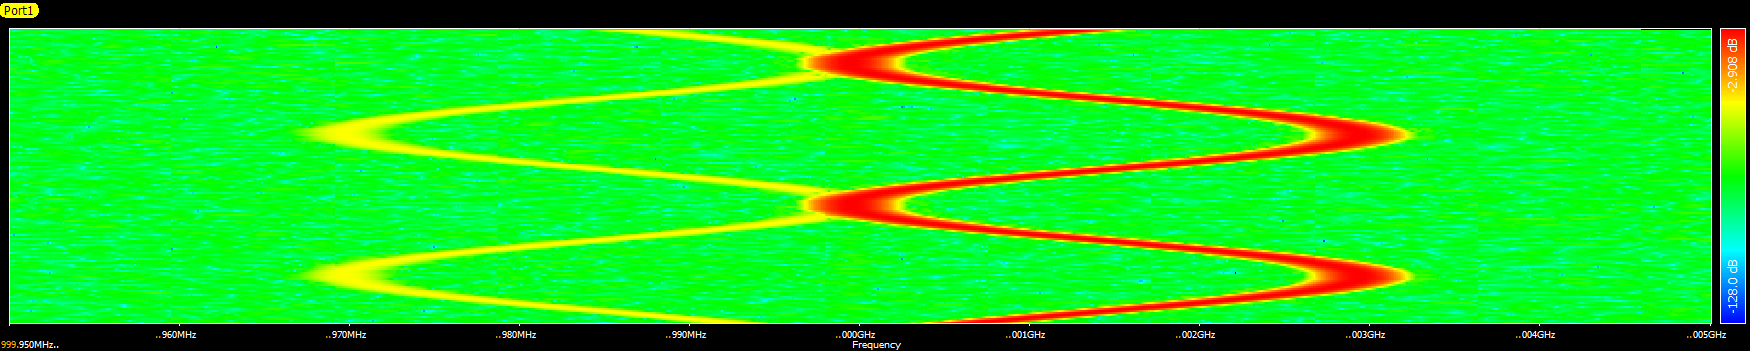
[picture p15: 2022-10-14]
Documentation/UserManual/Screenshots/GraphWaterfall.png

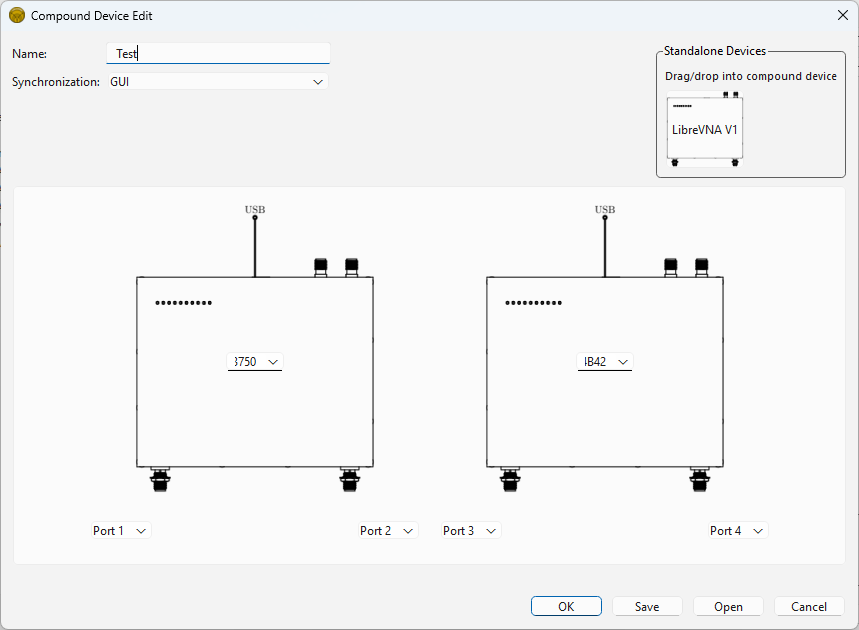
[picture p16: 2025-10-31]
Documentation/UserManual/Screenshots/CompoundDeviceEdit.png

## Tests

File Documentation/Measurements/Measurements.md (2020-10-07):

# Example Measurements

The VNA is still in a prototyping stage but some measurements have been done. The performance might still change slightly in future versions.

## VNA Measurements
Unless otherwise noted, all measurements have been taken after a SOLT calibration. The exported touchstone data for all measurements is included in this directory. In the screenshots, the colors of the S-parameters are:
* S11: yellow
* S12: blue
* S21: green
* S22: red

### Prototype_Isolation_SOLT
Both ports terminated into 50Ohm, SOLT calibration without isolation measurement. Up to about 3GHz the isolation is fairly good (with some difference between S12/S21 due to the layout). At frequencies higher than 3GHz it gets quite a bit worse.
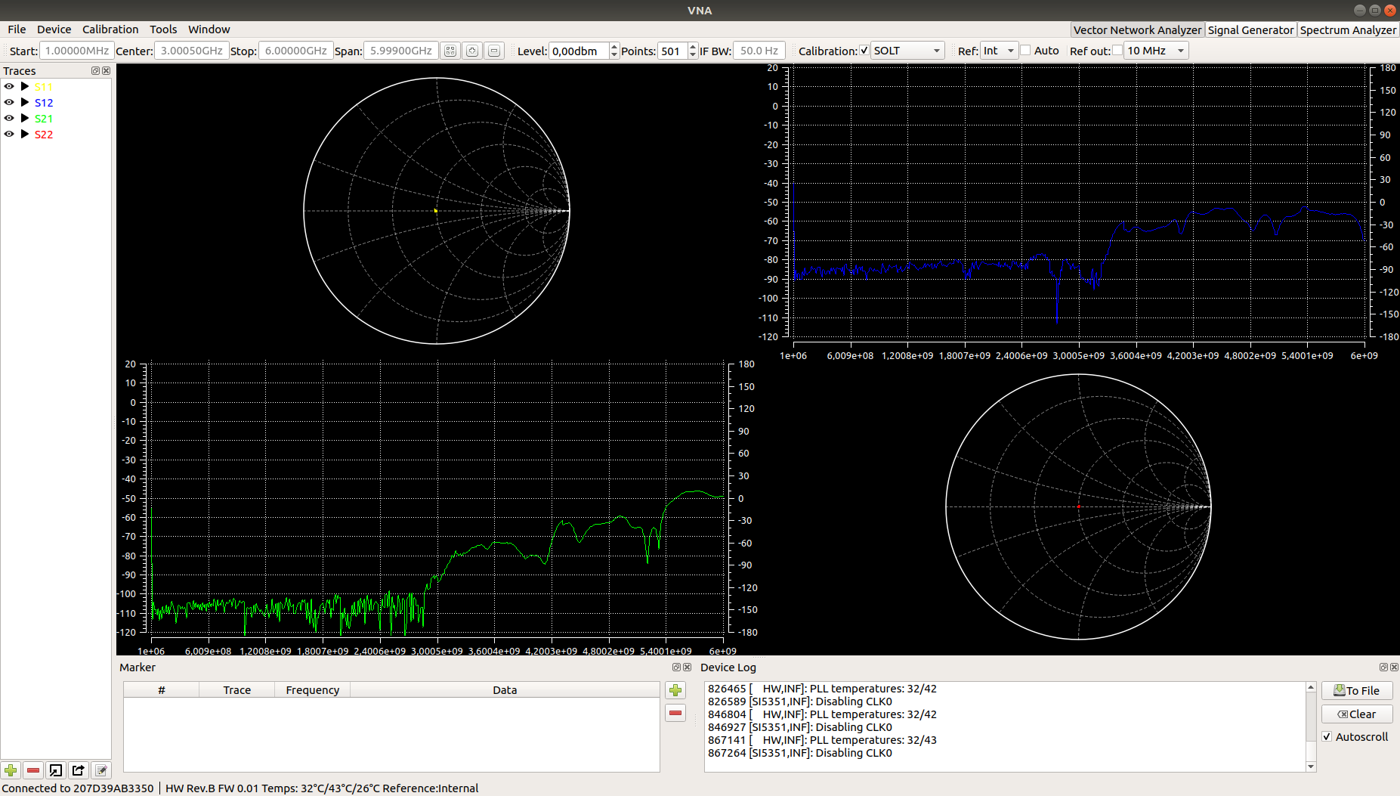
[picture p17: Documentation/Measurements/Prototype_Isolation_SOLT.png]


### Prototype_Isolation_SOLT+iso
Both ports terminated into 50Ohm, SOLT calibration with optional isolation measurement. This obviously improves isolation, but as soon as the setup is even slightly changed, most of the gained dynamic range is lost again.
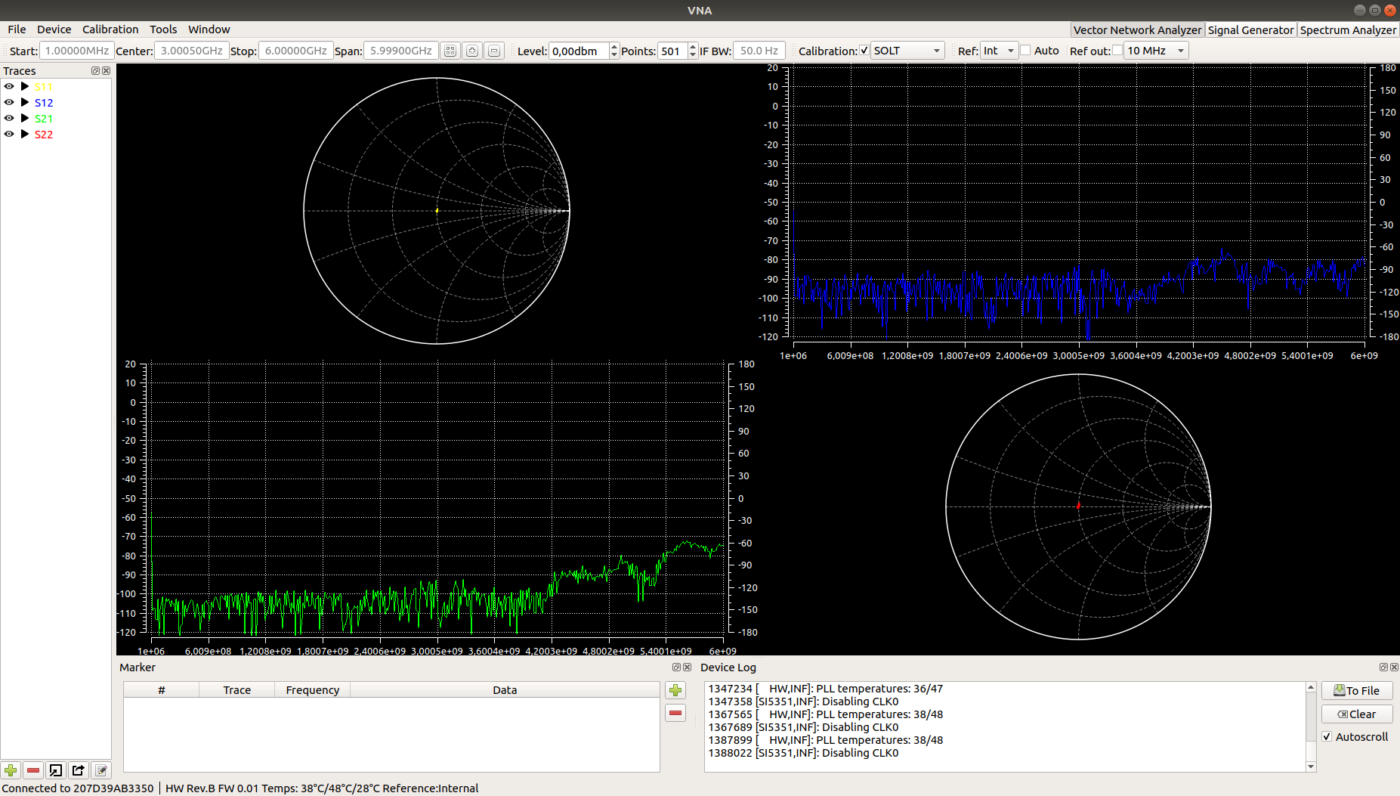
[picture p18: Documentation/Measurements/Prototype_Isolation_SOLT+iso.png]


### Mini-circuits_VAT-10+
Mini-circuit 10db attenuator connected between the ports.
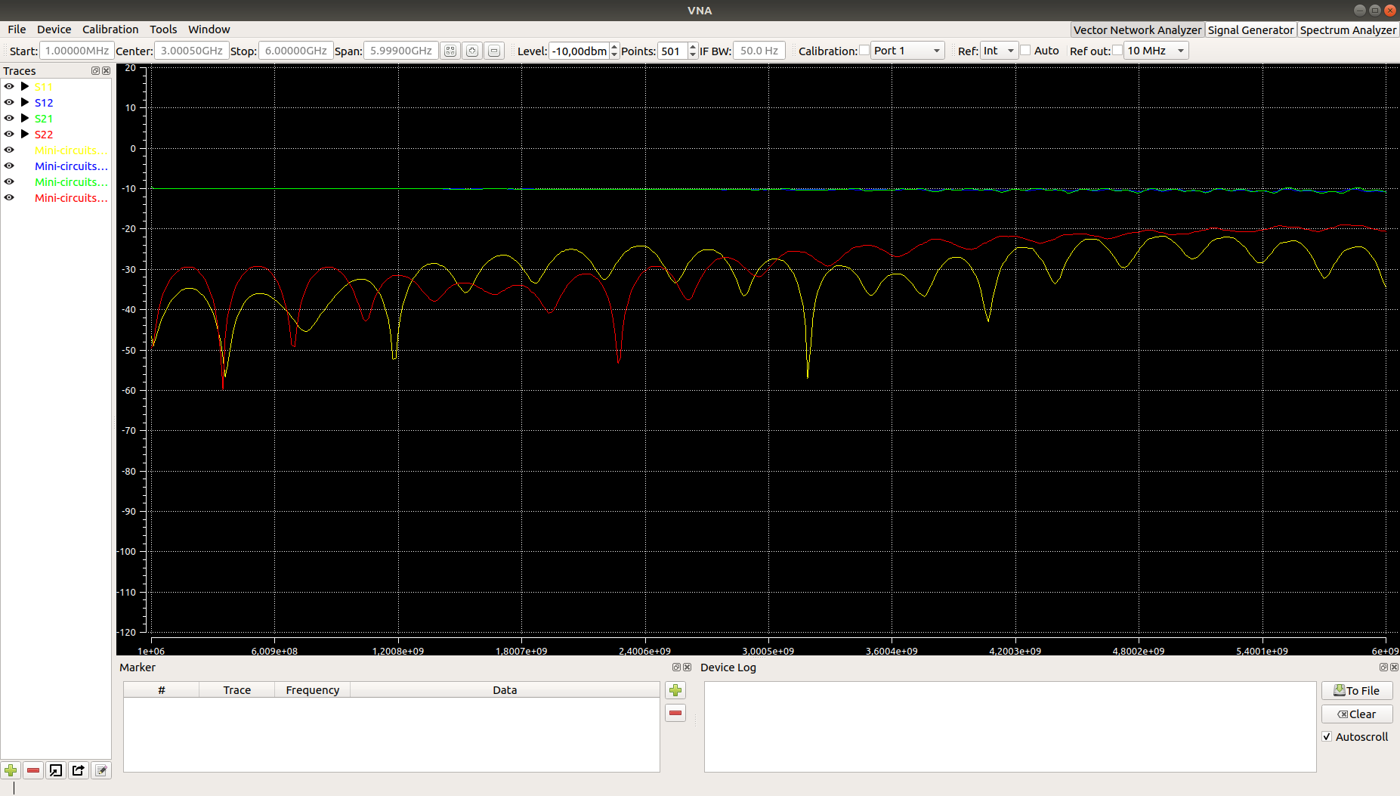
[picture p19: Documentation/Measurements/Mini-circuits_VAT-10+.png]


### Mini-circuits_VAT-6+
Mini-circuit 6db attenuator connected between the ports.
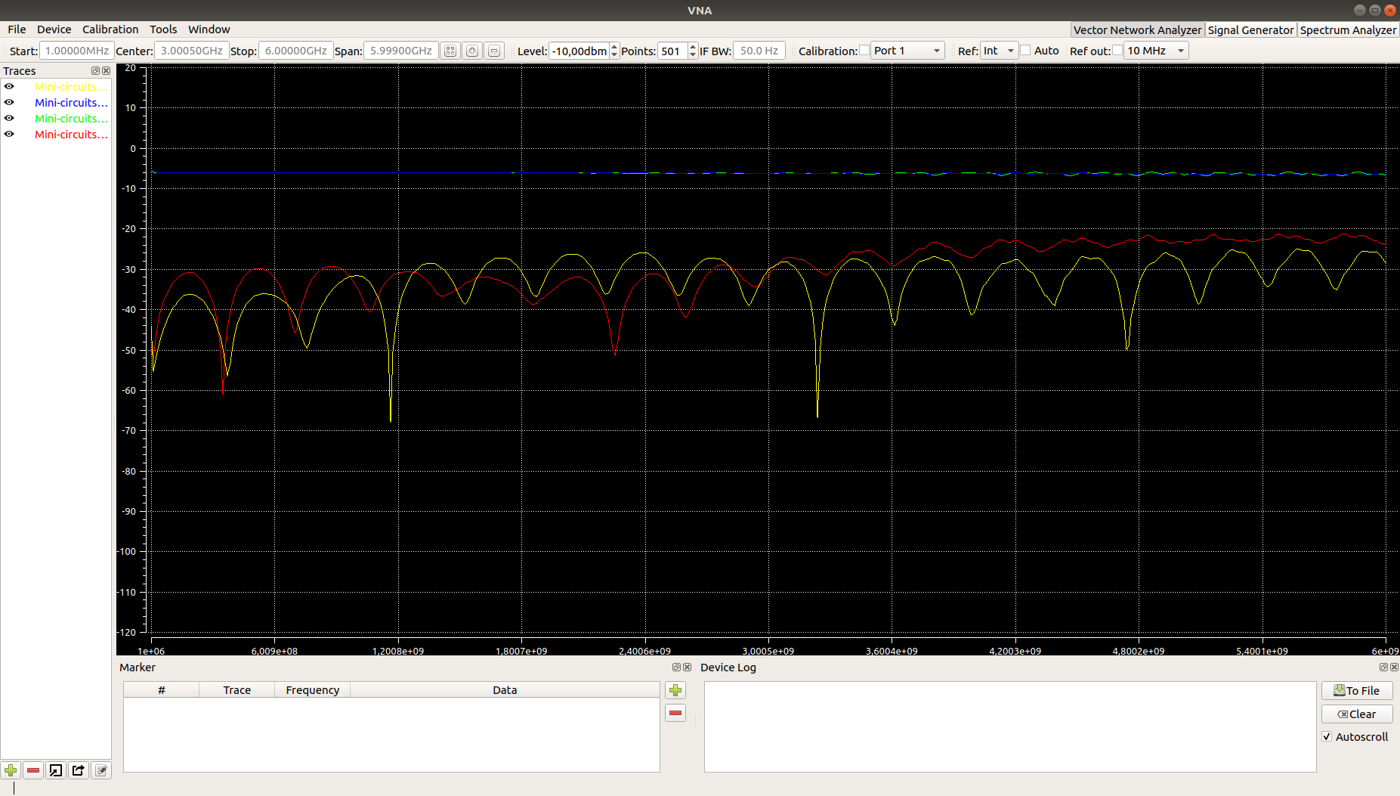
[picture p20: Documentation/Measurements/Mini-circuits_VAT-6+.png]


### Murata_RF1419D
403MHz bandpass-filter on small breakout-board connected between the ports.
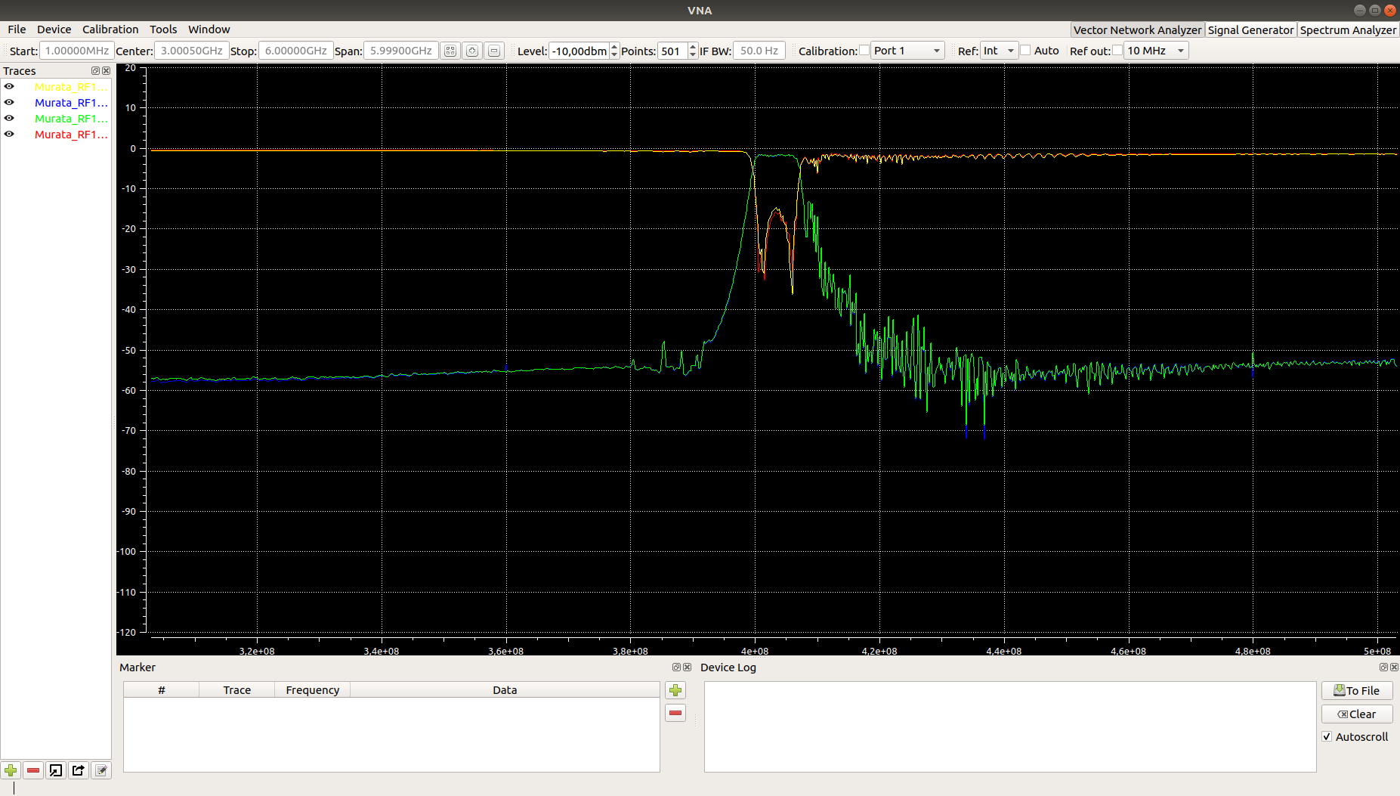
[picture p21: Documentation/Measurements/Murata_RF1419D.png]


## Spectrum Analyzer Measurements
**This device is designed as a VNA, not a spectrum analyzer. See user manual for limitations on spectrum analyzer measurements.**

### The effect of signal identification
The setup for the following two measurements is identical, except for the signal ID functionality:
* Center: 1GHz
* Span: 300MHz
* RBW: 10kHz
* Applied signal: Reasonable clean 1GHz CW tone with about 0dbm

With signal ID turned off, the resulting sweep looks pretty bad (only the 1GHz tone is really there, everything else is coming from the device itself, mostly due to aliasing):
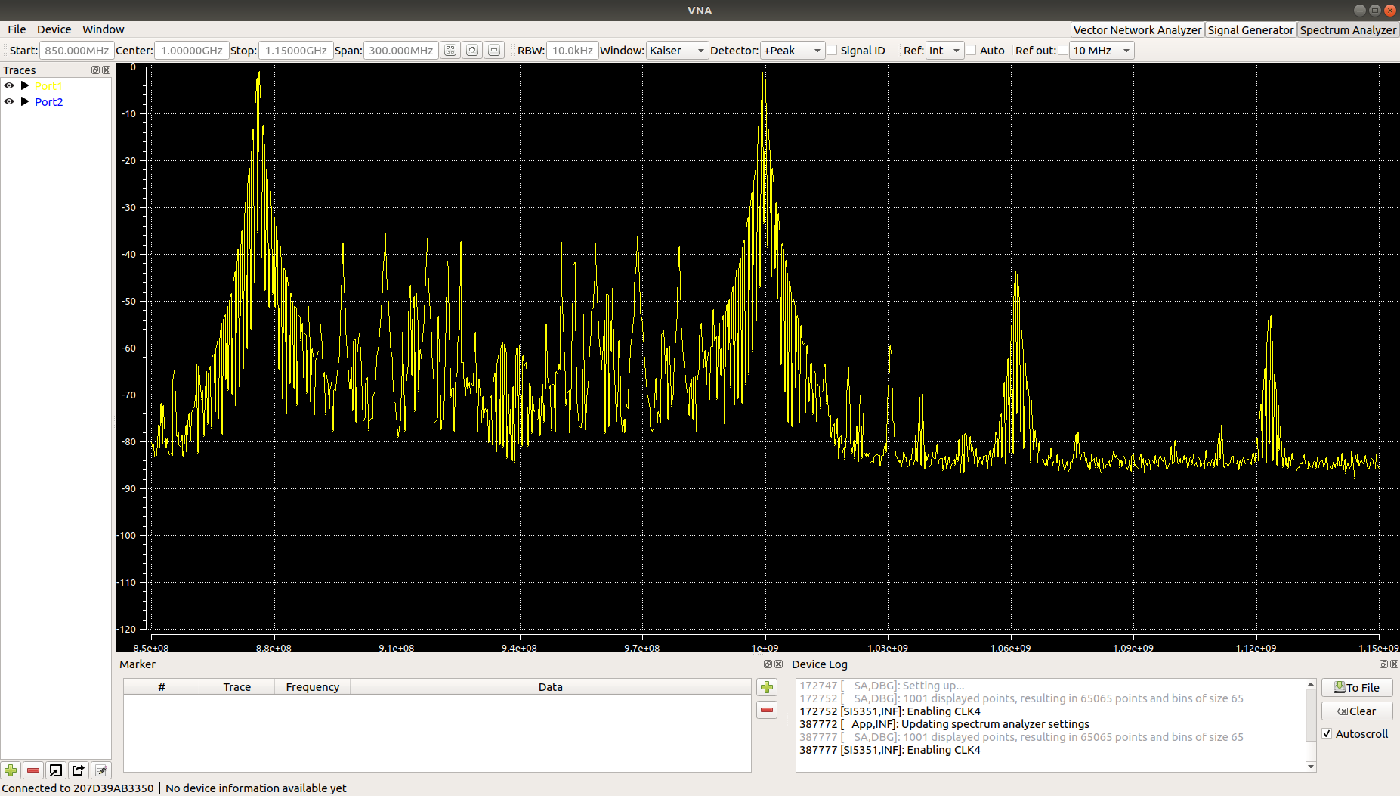
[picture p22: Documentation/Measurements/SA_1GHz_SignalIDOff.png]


When signal ID is enabled, most of the tones disappear. The result is still not perfect, but it should work for quickly checking whether a signal is there and getting a rough idea about its power.
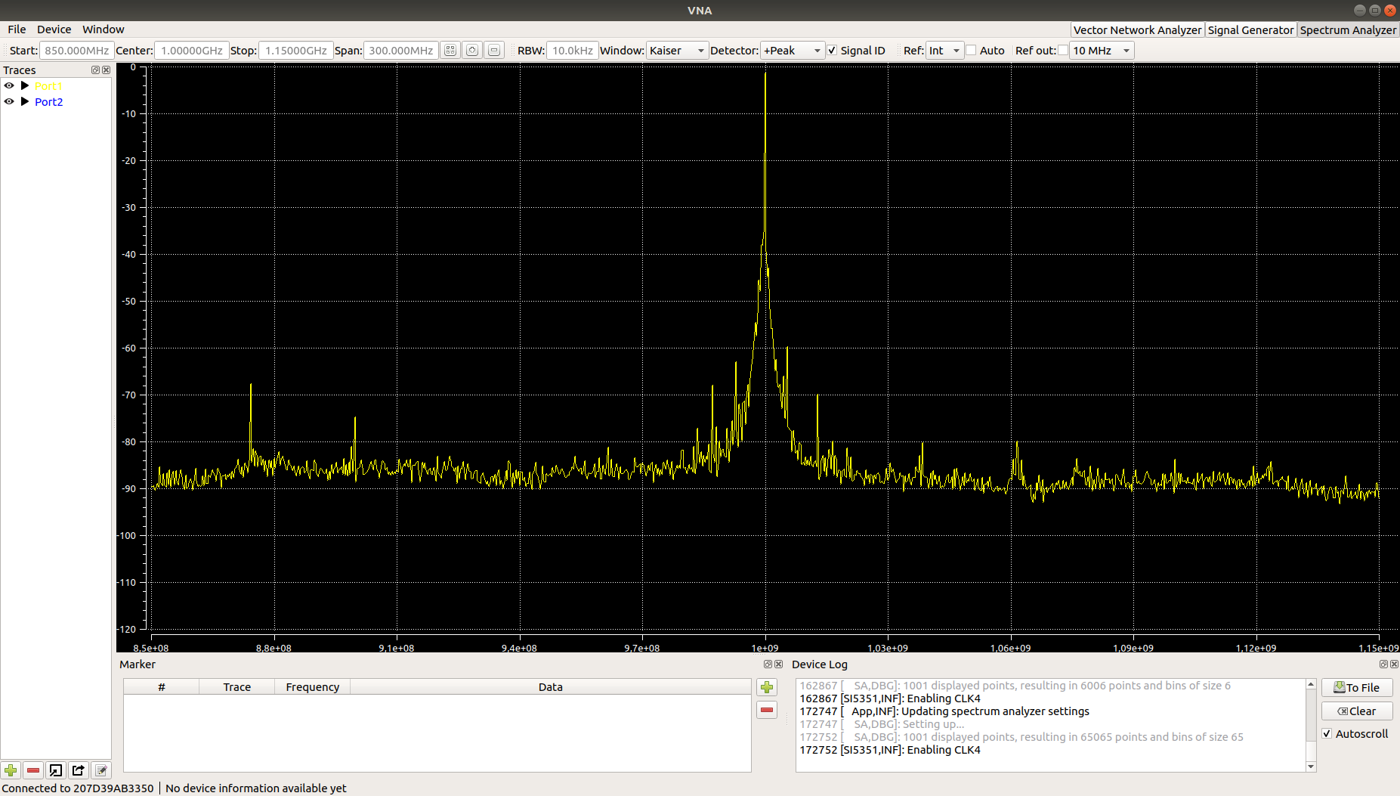
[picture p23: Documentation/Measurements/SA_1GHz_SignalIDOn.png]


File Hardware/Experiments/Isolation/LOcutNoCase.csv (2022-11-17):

Frequency | Port1 | Port2
4999500000 | 1.513360075e-06 | 0.0001812679548
4999501000 | 1.979116632e-06 | 0.0002128594788
4999502000 | 1.340454332e-06 | 0.000222300092
4999503000 | 1.226206336e-06 | 0.0001259127021
4999504000 | 1.123140464e-06 | 0.0002127806802
4999505000 | 1.941930122e-06 | 0.0002434307826
4999506000 | 1.712842732e-06 | 0.0002499943657
4999507000 | 2.592412557e-06 | 0.000136094488
4999508000 | 1.686951123e-06 | 0.0001718624844
4999509000 | 1.174191652e-06 | 0.0003284125996
4999510000 | 1.972939799e-06 | 0.000181313706
4999511000 | 1.551906053e-06 | 0.0001633110805
4999512000 | 1.376431783e-06 | 0.0002562346344
4999513000 | 1.633031047e-06 | 0.0002699169854
4999514000 | 1.378204843e-06 | 0.0002374303149
4999515000 | 2.7241515e-06 | 0.0003231113369
4999516000 | 1.732651299e-06 | 0.0002072128991
4999517000 | 2.65866538e-06 | 0.0001313267567
4999518000 | 2.113135679e-06 | 0.0001412697893
4999519000 | 2.578208523e-06 | 0.0001285923063
4999520000 | 1.397231927e-06 | 0.0003702848626
4999521000 | 1.641939662e-06 | 0.000186966703
4999522000 | 3.18671664e-06 | 0.0003040638112
4999523000 | 1.316437761e-06 | 0.0002206799691
4999524000 | 1.284739824e-06 | 0.0002498682588
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

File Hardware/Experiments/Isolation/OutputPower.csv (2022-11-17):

Frequency | Port1 | Port2
4999500000 | 2.153534297e-06 | 0.0002102516883
4999501000 | 2.342363587e-06 | 0.0002369037975
4999502000 | 1.245746262e-06 | 0.0001679893612
4999503000 | 1.049505499e-06 | 0.0003058116417
4999504000 | 1.641168296e-06 | 0.000243058108
4999505000 | 1.619538011e-06 | 0.0001527989953
4999506000 | 1.491658622e-06 | 0.0002259712492
4999507000 | 2.015177415e-06 | 0.0002686632215
4999508000 | 1.720785804e-06 | 0.0002273762075
4999509000 | 1.48370043e-06 | 0.0001978990913
4999510000 | 2.083226491e-06 | 0.0002217761066
4999511000 | 1.117617785e-06 | 0.0002591915545
4999512000 | 1.373498662e-06 | 0.0001974759361
4999513000 | 1.682379434e-06 | 0.0002123090817
4999514000 | 1.354453161e-06 | 0.0002241079346
4999515000 | 1.828269319e-06 | 0.0001245884341
4999516000 | 1.336191417e-06 | 0.0002538426488
4999517000 | 1.219352839e-06 | 0.0001947682031
4999518000 | 1.743238954e-06 | 0.0002048895258
4999519000 | 1.197050665e-06 | 0.0001943199604
4999520000 | 2.830842504e-06 | 0.0002388082648
4999521000 | 2.043674613e-06 | 0.0001451615972
4999522000 | 1.635220542e-06 | 0.0001883182413
4999523000 | 1.80042548e-06 | 0.0002079135593
4999524000 | 2.274143299e-06 | 0.0002675234573
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

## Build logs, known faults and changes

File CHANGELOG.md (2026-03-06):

# Changelog

## v1.6.5
Long overdue release with several small improvements:

- Bugfixes:
  - handle calibration data from log sweeps
  - PLL algorithm improvements, fixes small frequency deviations which show up at low IF bandwidths
  - Various UI improvements
- Quality of life improvements:
  - remember touchstone export settings
  - remember load/save paths
  - optionally prevent LibreCAL calibrations when temperature unstable
  - Dialog for viewing the active calibration model: Calibration->View error term model
  - Calibration can use already existing measurements (saves the user from attaching the calibrations standards again if the measurement is already available)
  - Improve marker handling when displayed at the very edge of a graph
  - Only load default calibration when initially connecting to a device, not when switching modes or closing dialogs
- New features:
  - new SOL calibration type (calibrates reflections only, possible to calibrate both ports at the same time)
  - Experimental SVG export options for images
  - Restore to default option for device configuration
  - SCPI API improvements:
    - Set/get calibration kit metadata
    - Allow spaces in arguments (for file paths)
    - Support lower case for calkit file names
    - Query the position in the current sweep
    - New commands for editing calibration kit standards
    - New command for dwell time
  
## v1.6.4

Critical bugfix for the embedded firmware:

- Fix SPI flash timing, see #315

Minor improvement for the GUI:

- Option to add titles to graphs
- Show trace names even when only enabled on secondary Y axis
- Add x axis variable to the available variables for formulas in "from math" traces

## v1.6.3

Bugfixes and quality of life improvements

- Windows and macOS: add icon to GUI application
- From math traces:
  - Validate formula immediately and show error messages
  - Bugfix: do not reset variable names when opening trace edit dialog again
  - Fix crash when combining with de-embedding
- Calibration:
  - Interpolate points using mag/phase instead of real/imag (minor improvements in accuracy)
  - Update widget when changing span
  - Fix race condition when aborting measurement
  - Reset LibreCAL port settings when aborting measurement
- Manual improvement: typos and wording
- Increase USB buffer timeout during sweep (should prevent disconnect when CPU is very busy)
- Include actual serial of connected device in SCPI \*IDN? response
- Allow group delay plot for reflection traces
- Configurable default Y axis limits per Y axis type
- Fix streaming server output for zero span sweeps
- Synchronization improvements for compound device
- Allow name changes for existing modes

## v1.6.2

Mostly bugfixes with only minor new features

- New features:
  - New SCPI commands:
    - Temperatures readout
    - Complete control over manual control via SCPI
  - Padding option for TDR/DFT to increase resolution
  - Support for dwell time (adjustable delay before each point in the sweep)
- Bugfixes:
  - Fix crash when deleting traces with TDR/DFT math
  - Spectrum analyzer: Improve tracking generator frequency accuracy
  - Fix swapped LO and Source unlock LEDs
  - Reduce amount of mode switches when starting and loading setups (faster loading time)
  - Use correct units on spectrum analyzer graphs (dBm instead of dB)
  - Fix Touchstone export file ending
  - Update eye diagram when changing settings while the trace data does not change
  - Keep eye diagram trace visible when other trace is deleted
  - Resolve math references when duplicating "from math" traces
  - Update LibreCAL API, detect LibreCALs with bad factory coefficients
  - Fix impedance renormalization (general formulas for parameter conversions)
  - Fix rare and random phase reversals of S parameter measurements

## v1.6.1

Mostly bugfixes with only minor new features

- New features:
  - New SCPI commands:
    - switch between linear/log sweeps in VNA mode
    - delete traces
  - Option to align axis ticks for left and right Y-axes
  - Import/export options in file menu
  - User-selectable handling of NaN values for limit checking
  - drop files on trace list to import them

- Bugfixes:
  - center TDR output values at zero (fixes impedance calculations in cases where there is a reflection from before the calibration plane)
  - fix calibration calculation when non-required S parameters are not available
  - improve LibreCAL coefficient extraction
  - use native OS dialogs for opening/saving files
  - future Qt version fix: prevent crash after taking calibration measurement
  - SCPI command handling improved
  - fix menus after loading setup files in certain scenarios

## v1.6.0

This update contains API breaking changes to the SCPI server. This was necessary because the previous implementation did not follow the standard completely. If you were talking to the SCPI server directly yourself, you will need to make the required changes. If you are using the provided libreVNA.py class, you just need to update that file.

- New featues:
  - New SCPI command: read/write preferences
  - New API: option to stream live trace data

- Bugfixes and improvements:
  - Keep de-embedding active when changing settings
  - Improvements to trace averaging
  - adjust SCPI API to conform better with the standard:
    - new required commands RST, CLS, ESE, ESR, OPC and WAI
    - no responses to commands, errors are reported through status registers instead
  - TDR updates happen during a sweep not just afterwards (with configurable update rate)
  - Additional sanity checks when loading calibration files

## v1.5.1

Mostly bugfixes with only minor new features

- New features:
  - Z0 of through standard now adjustable
  - Option to automatically adjust the span to the active calibration
- Bugfixes:
  - Make De-embedding menu visible on MacOS
  - Detection of handling of LibreCAL in the automatic calibration dialog
  - Allow updates of devices with older firmwares (a matching older GUI version had to be used previously)
  - Fix port excitation when not all S-parameters are measured
  - Do not use DFT in spectrum analyzer when in zero span mode
  - Readback of certain GUI values on Windows now correct (was stuck on 0 before)
  - Prevent crash when disconnecting the device while a dialog was open
  - Prevent occasional crash at the end of calibration measurements
  - Fix spikes in sweep when a frequency calibration is set
  - Improve sample timing between ADC and FPGA (resulted in very noisy traces on some devices)

## v1.5.0

- New features:
  - Further abstraction from the LibreVNA hardware. The GUI now supports VNAs with up to 8 ports
  - Capsulation of communication to the hardware inside of the DeviceDriver class. This simplifies the integration of drivers for other equipment
    - Experimental drivers for Siglent SSA3000X and SNA5000A series devices as examples
  - Allow cascading of muliple LibreVNAs, see Preferences->Device Drivers->LibreVNA/Compound. You need to configure a compound device first (consisting of up to 4 LibreVNAs). Afterwards, you are able to use them as one larger, virtual VNA with more ports (or more physical separation between the ports). Measurements within one physical LibreVNA will contain phase information, measurements between different LibreVNAs have their phase set to zero
  - Support for calibrating with sliding loads
  - New graph type: Eye Diagram
  - Restrict markers to a certain frequency range
  - Switched to a dedicated USB VID/PID thanks to pid.codes
  - Switched to Qt6
  - Easier 

- API-breaking changes: Unfortunately, some major rework was required to make the GUI compatible to devices with more than two ports. In some areas, the file storage format and the SCPI API had to change. Almost all changes are within the calibration system.
  - Calibration kit file format changed (old calibration kits can be imported)
  - Calibration file format changed (old calibration can be imported)
  - Calibration API changed significantly, see Programming Guide
  
- Lots of bugfixes, for example:
  - Fix X-label clipping on graphs
  - Prevent activation of a calibration without defined calibration standards
  - Fix isolation measurements for calibration
  - Valgrind issues fixed (mostly variable initializations)
  - made USB communication more robust
  - PLL locking issue fixed
  - no more disappearing device log

## v1.4.1
- Bugfix: Configure voltage regulator for correct voltage at startup

## v1.4.0

- New features:
  - Configurable constant lines for XY-plots
  - Limit testing on XY-plots
  - Single sweep functionality
  - Zero span support for VNA and SA
  - Math operations across traces
  
- Bugfixes:
  - Stop duplicate GUI elements from appearing when loading a setup file
  - Prevent wrong frequency output when sweep starts at DC
  - Improve automatic source/receiver calibration
  - Fix signal ID issue which caused valid signals to disappear at low RBWs
  - Changing trace color triggers replot of graphs
  - Remove output spikes in generator mode, caused by continuously reconfiguring the PLL
  - Fix MCU temperature calculation

- Small improvements:
  - Split plots without closing the plot first
  - Configurable marker sort order
  - Refactoring

## v1.3.0

Some new software features along with a few bug fixes.

- New features:
  - Allow multiple VNA/Signal generator/Spectrum analyzer tabs
  - Software work-around to allow up to 65535 points per sweep
  - Impedance renormalizetion (as de-embedding option)
  - Waterfall plot
  - CSV export options extended
  - logarithmic sweeps (logarithmic frequency steps)
  - Graph display improvements:
    - (Optionally) show units on all axes
    - Configurable font size
	- New Y axis options: dBuV, linear magnitude, unwrapped phase, group delay
	- Zoom feature for smith chart
  - User-selectable IF frequencies
  
- General bugfixes, among others:
  - Fixed valgrind issues (mostly uninitialized variables)
  - Prevent overflow in SCPI commands

## v1.2.1

Mostly bugfixes along with the occasional new feature.

- Calibration:
  - File format changed to json
  - Multiple measurements can be taken/deleted at the same time
  - Calibration kit allows separate male/female standards
  - configurable Z0 for short/open
- SCPI commands:
  - load/save calibration files
  - export to touchstone file format directly
  - additional command for reading trace data
  - fix typo in documentation
- UI improvements:
  - Additional Y-axis options: Reactance/Real/Imaginary
  - Graphs look a bit nicer
  - Configurable line width for graphs
  - finally added an application logo
- General bugfixes, among others:
  - PLL divider calculation fixed for certain frequencies
  - Improved USB buffer handling
  - Better error handling when opening invalid files
  - Various bugs when adding/deleting markers
  - graph autoscaling with invisible traces

## v1.2.0

- Additional SCPI commands
- Marker improvements:
  - create groups to move markers together
  - calculate additional parameters (R/L/C,...)
- Fullscreen mode of single graph by double-clicking
- Error flags for ADC overload and output amplitude unlevel in VNA mode
- New feature: power sweeps (sweep the stimulus power instead of the frequency)
- General bugfixes

Significant changes have been made to the embedded firmware as well as the FPGA configuration to support power sweeps. A firmware update on the LibreVNA is mandatory to use this new software version.

## v1.1.2

- Software:
  - Fix parsing of calibration kit settings

No changes have been made to the embedded software, updating the firmware on the LibreVNA is not required.

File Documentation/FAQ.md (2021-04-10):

# FAQ

### How did this project start?
Initially, the VNA consisted only of some breakout boards of various RF chips that I designed and used to get some experience with RF design. Once the result seemed reasonable good, I decided to built everything into one PCB and create an enclosure for it, [this device](https://github.com/jankae/VNA) was the result.

I didn't plan to do anything with this beyond this initial prototype but several people got interested and, thanks to Hugen, development continued. However, this is still just a hobby project of mine. I'll keep improving it as best as I can (and find the time for it) but please do not expect professional level support.

### Will it stay open source?
Yes. No matter what happens this design and all future improvements by me will be published on my GitHub account (same as all my other projects).

### Can I buy one?
Yes, an initial batch is available at Aliexpress. Production and sales is handled by Hugen, I am not directly involved in the sales process.

### Can I build one?
Absolutely. All required files are available and if you are not afraid to solder a lot of small components you can certainly build your own. The total BOM cost (without the aluminium shielding) is about 200€ when only buying parts for one PCB.

There are some [basic instructions](DeveloperInfo/BuildAndFlash.md) to help get started on the software side.

### I noticed X good be done easier/better
You are probably right. Development of the VNA consists of several different parts (schematic, RF layout, embedded firmware, FPGA configuration, GUI application, digital signal processing,...) and I am certainly not an expert in all of them. Please get in touch if you have ideas for improvements (write a mail or create an issue).

### Why the dual stage conversion?
There are some advantages to having the second stage mixers (mostly to compensate for limited fractional dividers in the MAX2871) but for most operations, a single stage conversion would probably work almost as well. However, compared to other parts the cost for the second stage conversion is not that high and without it certain functionality would not be available (e.g. spectrum analyzer mode with low RBW). There is a bit longer explanation [here](https://github.com/jankae/VNA2/issues/2#issuecomment-700218226).

### Why are there no aliasing filters in front of the ADC?
The actually are RC lowpass filters in front of the ADC but they are not very sharp and even for signals way above the nyquist frequency they only provide a small amount of attenuation. With my combination of final IF and ADC samplerate, proper alias filters are difficult to implement. Thankfully, they are not absolutely required in a VNA (same reason why image reject filters reject filters after the mixers are not required: the device already knows which frequency to look for, because it generates the stimulus signal itself).

However, in spectrum analyzer mode, all these missing filters are a problem and lead to a lot of images that have to be removed by signal identification. 

### Why is the final IF so high?
I am using 250kHz as the final IF frequency. Compared to some other VNA projects this is rather high and requires a fast (more expensive) ADC. However, it also makes the sweep rate faster: each measurement point takes at least one IF period (more if noise should be reduced to practical levels).

### Why the FPGA?
Why not sample the ADCs directly with (a more powerful) STM32? Or even use the ADC on the µC itself?
* I wanted more than the 12bits provided with by internal STM32 ADCs (and also better SNR)
* Sampling the three 16bit 1MSamples/s ADCs with an STM might be possible but certainly would be a challenge
* More flexibility with the FPGA controlling all critical RF components (e.g. setting up all PLLs concurrently for each measurement point, further increasing sweep rate)
* Enough power for future features (e.g. spectrum analyzer mode with FFT)

### If there has to be an FPGA, why one with a closed-source toolchain?
* Sorry, thats just what I had experience with (also, the toolchain is free, just not open-source)

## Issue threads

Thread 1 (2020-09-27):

Hardware Schematic/Board conversion to KiCad 5.1.7-1

bvernoux, 2020-09-27:
Your project is just amazing and It will be even better if the Eagle files could be converted (and fixed) to KiCad 5.x
I will check that on my side but anyone interested in doing the conversion are welcome

jankae, 2020-09-28:
If you try the conversion be sure to use the newest eagle files (small differences to the pictured PCB). Last time I tried KiCad I didn't like it that much but that was a couple of years ago and from what I heard it improved a lot since then. If someone can pull off the conversion, I'll seriously consider switching from Eagle to KiCad on this project

chrisgj198, 2020-09-28:
Could you please include at least a .pdf of the schematic, for us Kicad users? I think none of my machines have Eagle installed any more.

jankae, 2020-09-28:
Of course, here you go: 294855a

bvernoux, 2020-09-30:
Does some people are interested by the conversion to KiCad 5.x (or even 6.x) or I'm the only one ?

jankae, 2020-09-30:
I'd like the chance to take another look at KiCad, it is just not that high on my priority list. At the moment I am fixing small mistakes/making tiny improvements on the hardware side and I am going to do that with Eagle. I do realize that this board is not covered by the free version of Eagle and for future development switching to KiCad would probably help a lot of people.

I am not going to touch the PCB files for a while after I have made the changes for the next revision (will probably take another week or so) and I think that would be a good time to try a KiCad conversion. But as I don't have any experience with KiCad I am not sure of how much help I can be.

nbgsmk, 2020-09-30:
Personally I never used KiCad, but I see no reason why someone experienced wouldn't be able to try with the existing board, just to see the problems and quirks, and to perfect the process, in the meantime. I wish I could help but I'd probably be spending all time on my own learning curve.

bvernoux, 2020-10-01:
@jankae I'm waiting your feedback when the schematic/board will be frozen I can do the conversion to start on a clean 1st version with KiCad

bvernoux, 2020-10-03:
For information I have filled 2 issues in KiCad nightly related to Eagle 9.3.1 import:
- Eagle 9.3.1 import unsupported Eagle layer 'tRestrict' (41), 'bRestrict' (42) and 'Milling' (46)
   - https://gitlab.com/kicad/code/kicad/-/issues/5862
- Eagle 9.3.1 import with PCBnew freeze during DRC Control
   - https://gitlab.com/kicad/code/kicad/-/issues/5863

jankae, 2020-10-07:
@bvernoux I finished making the small changes to the PCB and most likely will not touch the Eagle-files for at least a few weeks or even months. Regarding the unsupported layers:
* tTest: Only contains the coordinates of the testpoints, not needed for correct board files
* tRestrict/bRestrict: I used these layers to keep the ground plane away from a couple of RF traces. In Altium I would have used a specific clearance rule between the nets and polygons but as far as I know Eagle does not support that. If KiCad can be configured to do that with DRC rules, there is no need for these layers
* Milling: Only used for pads on the USB-C and power connector (weird work-around because Eagle does not support arbitrary pad shapes)

What is the reason for using KiCad 6.x instead of 5.x? Are there any required features that are only available in the 6.x version? As 6.x is not released yet, I would've expected to use 5.x, but then again I don't really know anything about KiCad, maybe there are good reasons.

I tried importing the project into KiCad a couple days ago and was quite impressed how easy that seemed to be. Apart from the unsupported layers, I think the removed soldermask between the RF sections wasn't imported correctly (only the outline was visible in KiCad), otherwise it looked good at first glance.

sp9bsl, 2020-10-07:
Hi Jan,
I'm very impressed with your work. I'm considering ordering one small batch of pcbs for private use. You mention about Altium - do you have the pcb/schematics files designed in Altium?

Slawek

jankae, 2020-10-07:
Hi Slawek,
thank you for the compliment, if you do replicate this project please send me pictures/feedback. There are no Altium files, I just used that as an example because thats what I am used to at work. At the moment the only PCB files for this project are created in Eagle.

sp9bsl, 2020-10-07:
Of course, will send pictures. I will wait some time watching what Hugen will do. The ready to buy working version is better option - less time consuming :)

bvernoux, 2020-10-07:
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

I will check to do it on KiCad 5.1.7-1 (latest stable version), so far I have tried on KiCad 6.x nightly build because there is some nice features I have tested... but the aim is to do it for KiCad 5.1.7-1 as it is very stable.

>
> I tried importing the project into KiCad a couple days ago and was quite impressed how easy that seemed to be. Apart from the unsupported layers, I think the removed soldermask between the RF sections wasn't imported correctly (only the outline was visible in KiCad), otherwise it looked good at first glance.

Yes the import is already very nice and with some minor tweak it is fully usable.
I have already the full schematic converted to KiCad 6.x with 0 Warnings and the Board is not far to be very nice (some part shall be fixed but I have noted everything).
I will do that on KiCad 5.1.7-1 with the latest version I have found some very nice hints for the shielding to create some masks from the 3D step parts using FreeCad => InkScape => Paint.net (or any open source tool) => KiCad, I will document it more for others.
Example of actual conversion on Kicad 5.99 nightly (5.99.0-3741-gb38cef409)

Schematic:
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

Board:
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

3D Board Preview Top:
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

3D Board Preview Bottom:
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

bvernoux, 2020-10-21:
If you are interested I'm not far to release the schematic/board files for KiCad 5.1.7-1 especially with hint how to extract the KiCad Mask from STEP file for the shielding using only open source tools of course

kf4mot, 2020-10-21:
Stepup may be a good tool for this project if someone is interested in some Kicad/Freecad integration. https://kicad-pcb.org/external-tools/stepup/

jankae, 2020-10-22:
@bvernoux I am definitely interested in the KiCad files, thank you doing the conversion. Unless I find KiCad extremely awkward to use after spending a bit of time with it, I will eventually move away from Eagle on this project.

bvernoux, 2020-10-25:
Conversion done see https://github.com/jankae/VNA2/pull/7

jankae, 2021-04-17:
As KiCad does not support round soldermask regions for now, I decided to stay with Eagle. I'll check the KiCad features from time to time (as some of the required stuff is being worked on, see e.g. https://gitlab.com/kicad/code/kicad/-/merge_requests/731) and once it supports everything I will gladly switch to it

Closed 2021-04-17.

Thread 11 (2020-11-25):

Plot corruption - ratsnest

nbgsmk, 2020-11-25:
Hello Jan!
I noticed a strange bug, apparently device in initialization, when switching modes. I was struggling for two-three days to reproduce it, and finally, here is how:
Start app (goes into vna mode)
(possibly switch to spectrum analyzer but sometimes even without this step)
switch to signal generator
enable port 1, disable port 1 (or port 2, regardless)
switch to vna mode

After this:
Graphs become like a ratsnest (attached pics)
Only usb cable (re)connection helps, ie the device needs to be rebooted.
Funny thing, just now, I was back in vna mode, opened the window for manual control, closed it without making any changes, and things are back to normal.

I am not really sure about the followng, but _maybe_ device temperature plays a role. Currently it is 50/59/34, but in the screenshot I took, it was 28/38/21. I want to say, I am swithching modes very very often, and 'torturing' the vna :-) with all kinds of possible and impossible settings. Just this morning, after using signal gen. mode, and back to vna, nothing unusual happened. Several times. And now, after 2-3 hours, I can reproduce it reliably. I noticed this a couple days ago, but back then, I couldn't reproduce it at all. So I am not sure if temperature has anything to do with it.
Just now comparing my notes ;-) and it seems, a couple nights ago, I could not reproduce the issue later during the session. I want to say, at the time I concluded it has to be cold to show the problem. And today it's the opposite. So please, take my thoughts on temperature with some degree of suspicion. :)

I would not consider this a high priority issue, as it happens relatively rarely, and there is an easy way out of it. Just by full init between modes, or a reboot (I'm sure it's lightning fast) and we would never notice it.
I'd try to chase it myself, but my understanding of hardware specifics, registers, and especially fpga, is not enough for independent troubleshooting. Not yet. However, if you take the time for this issue, and have any suggestions and requests for me, I am willing to do anything. :-)

Has anyone else noticed this on their device? I hope other people are reading, too. How are your temperatures under prolonged operation?

Regardless, here is a suggestion:
- add option in the menu to reboot device, what do you think? Or in the manual control window?

Cheers!
Zoran

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

jankae, 2020-11-25:
This is definitely a firmware bug, it looks like the source does not get enabled when switching modes in the way you described. Without the source, all receivers essentially see no signal (only noise), so all S parameters are really noisy and at 0db on average. Which version (git commit) of the firmware and PC application did you use?

> Just by full init between modes, or a reboot (I'm sure it's lightning fast) and we would never notice it.

There is already a full FPGA reset between modes (noticeable by the "ready" LED turning off shortly). But looking at it now, I think I broke something in one of the latest updates. It is not doing the reset when switching to/from the signal generator. I'll look into it.

jankae, 2020-11-25:
978842a should fix this, let me know if you still see the problem.

> How are your temperatures under prolonged operation?

Up to 60°C after several hours. Already uncomfortable to touch but okay for the electronics. According to report from another user, adding a fan keeps the temperatures below 30°C but personally I prefer the silent fanless operation.

I wasn't aware that you already have the hardware, did you got one of the samples from Hugen? Or did you build it yourself?

OneOfEleven, 2020-11-25:
That rats nest I've seen with my software too. Yes it's a firmware problem. I worked out how to get around it so as not to see it again but that's not a fix for the problem, a firmware fix is the only answer.

nbgsmk, 2020-11-25:
As far as I can find my way around Git in Qt Creator, I checked the latest graph-update branch.
In paralell, I use IntelliJ IDEA (a beautiful Java IDE from JetBrains) to verify what I am doing. It turns out, you can open the same projects and folders with both of them at the same time and it works flawlessly. What I do in Qt Creator, immediately is shown in IntelliJ and I can confirm all the edits, branches and differences in a very friendly and pretty gui-like interface. To revert to the short answer, I pulled the latest graph-update from this morning.

Regarding the hardware, I got a sample from kind Mr. Hugen, thanks to him **a thousand times!** 🥇 👍
I was about to build one or two for myself, but Hugen kindly offered his help. By the interest this has produced in me (decided to install and learn Qt basics just because of this), and judging by the amount of time I spend every day playing with it, and contributing here-and-there, I hope I am justifying his generous intervention, so to speak. :)
Zoran

nbgsmk, 2020-11-25:
Just tested the latest FW:
- updated to the latest ver., tested the issue as described - problem no longer present
- downgrade to previous - able to reproduce the problem
- upgrade to latest again - issue fixed.
I propose to close this.

nbgsmk, 2020-11-30:
Sorry, could not resist commenting, although closed.
I ran my VNA for 12 hours straight (!), actively working on it/with it. It was laying on a textile surface, so not very heat conductive.
It got upto maybe ~65°C but not higher.

> Up to 60°C after several hours.

sp9bsl, 2020-12-01:
Hi,
my device laying on the desk, after about an hour reports around 50°C. Placing a 90mm 12V fan on it, with 5V power supply (almost noiseless) causes temperature to fall around 25..30°C.

I also have the sample from Hugen (arrived last Friday), I want to thank him for his kindness!

Slawek

Closed 2020-11-25.

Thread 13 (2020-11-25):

Feature proposal: over-temperature protection

nbgsmk, 2020-11-25:
Jan, another thought on temperatures.
I discussed with Hugen briefly and he assures me that most of the heat comes from the mixers and plls, so any kind of slowing down the acquisition rate would not give any reduction in temperatures. Is that true?

Yes or no, but possible fimware feature comes to my mind:
in case of any dramatic increase of temperature (since we are already measuring), how about an internal shutdown of some kind, to save the device before damaging itself?

jankae, 2020-11-25:
> most of the heat comes from the mixers and plls

Yes, that is correct. Power consumption is about 6W (depends a bit on the operating mode) and the two PLLs (source and 1.LO) together with the three first stage mixers use about 3.6W of that. The rest is split between the second stage mixers, various LDOs and of course the ADCs and FPGA. Using lower ADC samplerates could save a little bit but it won't really make a significant difference.

Over-temperature shutdown could be useful feature but I won't work on that anytime soon (unless you operate the VNA in something like a 60°C environment, it will not damage itself). I'll put it on the list and if I ever get bored, I'll implement it ;) And of course you are always welcome to add it yourself :)
By the way: while you can disable the PLLs, the mixers don't have a true shutdown. The only way to really get the consumption down would be to shut down the 6V rail, but that is not possible without changing the hardware.

nbgsmk, 2020-11-25:
Nice challenge. I will have that in mind. In case I get bored :) :)
> I'll put it on the list and if I ever get bored, I'll implement it ;) And of course you are always welcome to add it yourself :)

OneOfEleven, 2020-12-02:
It does sometimes get very hot to touch , particularly if I'm running it quite fast.

Here's a speeded up video (original length is 3 minutes) showing the S11 drift immediately after a Load/Isoln (50R loads on both ports) re-calibration, the S21 quickly follows after but my arms gave out holding the camera.

https://youtu.be/vRYIbsdYJuw

I don't like relying on fans, noisy or otherwise as it's more cumber sum, requires more power and adds a failure point, passive cooling is the best.

nbgsmk, 2020-12-02:
I couldn't quite see on your video, if upper curve is S11, and how big is the drift?
Funny thing, it gets a less noisy towards the end. How do we explain that?

> Here's a speeded up video (original length is 3 minutes) showing the S11 drift immediately after a Load/Isoln (50R loads on both ports) re-calibration, the S21 quickly follows after but my arms gave out holding the camera.
>

OneOfEleven, 2020-12-02:
> I couldn't quite see on your video, if upper curve is S11, and how big is the drift?
> Funny thing, it gets a less noisy towards the end. How do we explain that?

Yes the upper brown curve is S11, the lower blue curve is S21.

Thinking out aloud I'd say it gets less noisy because it's moving up away from the noise floor, and so the base noise level has less effect on the signal that is received from the RF bridge sensor area. But I can't say for sure as I don't yet know the exact cause for the large changes my unit goes through with temperature. I will take the cases off and re-clean and re-thermal compound the areas (again) that contact the various chips for heat sinking, will see if that helps. The case does get quite hot so I'd say the thermal contact areas to the chips are working well as is, other wise the case wouldn't get so warm in a short space of time.

I don't know if you guys want me to report these happenings or not really, please let me know either way really, I really love the VNA so want to help. It makes the Nano's feel like toys when I go back to them.

jankae, 2020-12-03:
I am thankful for every reported problem or suggested improvement, so please keep posting any issues you might find. I might not always be able to do something about it, but I always add it to my long list of possible improvements.

nbgsmk, 2020-12-07:
Inspired by @pentti12   https://github.com/jankae/VNA2/issues/14#issuecomment-736566119  I put mine on an old uhf amplifier. No big deal about the amplifier, it's just a larger metal block I had (no heatsink in the lab, can you believe it!). The idea was to see if I could lower the temperature with very little effort. Now it barely reaches 45-50 degrees after several hours, which I find excellent (used to go up to 65deg.). I will find a nicer heatsink and I consider this "problem" permanently solved.
But Jan's challenge to add some kind of over-temperature protection in firmware, that one remains. ;-)

blackberryer, 2020-12-22:
> Inspired by @pentti12 [#14 (comment)](https://github.com/jankae/VNA2/issues/14#issuecomment-736566119) I put mine on an old uhf amplifier. No big deal about the amplifier, it's just a larger metal block I had (no heatsink in the lab, can you believe it!). The idea was to see if I could lower the temperature with very little effort. After several hours, now it hovers at ~45degrees +- a few, which I find to be excellent (used to go up to 65deg.).
> I will find a nicer heatsink and I consider this "problem" permanently solved.
> But Jan's challenge to add some kind of over-temperature protection in firmware, that one remains. ;-)

Hi,nbgsmk
What material is the shell you use, and I am considering which material has better shielding effect.

nbgsmk, 2020-12-23:
Hello,
I believe this is some variant of aluminum, although I didn't make the shield myself so it was not my choice.
In terms of rf shielding, as long as you don't use silver or gold-plating, in my oppinion there should not be much difference between other common metals.
I believe aluminum is used most often due to best compromise among price, thermal characteristics and ease of machining.
Regarding thermal, the bottom block is also aluminum, just differently anodized (if that is the right english word).
I would be glad to hear if someone has more scientific info than just my oppinions.
Zoran

hedleyd, 2021-01-02:
When my board is finished I plan to take an IR photo as unit warms up then machine another layer of aluminium which will have small noctua fan blowing air through cooling channels which will be routed in the extra alu layer over hot spots - these fans are really quiet

DiSlord, 2021-02-01:
Here is termal foto of my device
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

nbgsmk, 2021-04-18:
Hello Jan!
Just considering this part-time, not ready to implement yet. Lowest priority question... :)
I'm thinking two options:
a) Check every device log message within the pc application->DeviceLog::addLine. Search the string for "temperature" + some arbitrary limit (suggestions?) and alert if it is crossed. Easiest way, but searching for a literal string like that is a bit of a hack, imho.

b) In the embedded application->Hardware.cpp, below this
```
GetTemps(&tempSource, &tempLO);
LOG_INFO("PLL temperatures: %u/%u", tempSource, tempLO);
```
check if temperature is over a limit and send additional eg. LOG_CRIT. Capture that in the PC application.
Since I only use STMCubeIDE, I can not build the embedded app and test this myself.

It seems device log messages can be captured even if the device log dock is closed, so the idea looks ok.

In any case, if we proceed: how to handle this event in the PC application? Warning popup only, (suggest) device disconnect or something else?

Ideas, comments? Thanks!

jankae, 2021-04-18:
> Check every device log message within the pc application->DeviceLog::addLine
The string for that line is created from the DeviceInfo packet, it would be easier to use the temperatures of that directly instead of converting the string back to a number. But I think the overtemperature handling should be done by the device (in case of a hardware upgrade with possibly different temperature limits the application should not have to handle that).

I'd suggest adding a status flag to the DeviceInfo struct. There are already error flags for other conditions, a "overtemperature" flag could be added easily. The implementation is not difficult but what should happen? Maybe disable whatever hardware can be disabled (mixers will stay active) and show a warning to the user?

nbgsmk, 2021-04-20:
> The string for that line is created from the DeviceInfo packet, it would be easier to use the temperatures of that directly instead of converting the string back to a number. But I think the overtemperature handling should be done by the device (in case of a hardware upgrade with possibly different temperature limits the application should not have to handle that).

> I'd suggest adding a status flag to the DeviceInfo struct. There are already error flags for other conditions

Agree on all points.
Getting the temperature from the log line string is a hack, for sure. I already didn't like my own idea :) :) I just couldn't find the right place for it. So thanks for the suggestion!
I will look into that.

What should happen? Well, exactly that: disable what is possible, issue a warning. if the device could handle this alone, it would be very bullet-proof (imagine a problem when powered through a DC jack and pc not connected).
The only further action I can imagine, is maybe that a pc application issues a device disconnect. But is this any different in terms of what gets disabled or stays powered on? And do we need to go that far?
Sorry I tend to overkill error checks and protection issues ha ha...

jankae, 2021-04-21:
> But is this any different in terms of what gets disabled or stays powered on?

There is no difference in power consumption between setting the device to idle and (logically) disconnecting the USB (physically disconnecting gets you down to zero of course). In both cases, the PLLs, amplifier, second stage mixers, ADC drivers and ADCs are powered down. The first stage mixers are always active as they don't have a true shutdown feature.

In my mind the perfect over-temperature protection would work like this:
* a hard temperature limit (e.g. the max. operating point of the PLLs, +85°C). If this temperature is exceeded, the device itself goes into idle mode (and maybe disconnects the USB?)
* a configurable soft temperature limit with a user-selectable action (e.g. do nothing, just display a warning, set the device to idle)

Some hints for a possible implementation:
In the device firmware:
* check for the hard limit and and disconnect the USB (off the top of my head I don't know how to disconnect, but it should be possible in the USB driver) and set the hardware to idle mode if it is exceeded
* Add an over-temperature flag to the DeviceInfo struct, send a message with this flag set just before disconnecting (so the application knows what is happening)

In the GUI:
* Add the soft temperature threshold and the selectable action (QComboBox?) to the preferences dialog
* Whenever a DeviceInfo message is received, check the temperatures in that and trigger the selected action if threshold exceeded
* If at any point the over-temperature flag is set in the DeviceInfo, disconnect the device (it will do so on its own anyway) and show a message about that

Let me know if you want to take that on (or need help along the way)

lucasub, 2022-09-08:
It would be interesting to be able to buy the heatsink specially designed for this tool. It would be the quickest way to fix the problem. I think that for 30 ... 100 € everyone could buy it without having to waste time making one with definitely higher costs and with a worse yield.

Closed 2023-10-23.

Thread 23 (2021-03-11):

JLC only takes gerber or other EDA formats, would you please export one in the project?

taskx6004, 2021-03-11:
Hi,

Thanks for your effort and making it open source. After about a year's free time search online RF projects I found your design is the most doable challenge to begin my journey in RF hardware.

I am very interested in making a small batch of PCBA from JLCPCB. I have previous experience with them and it was successful. After checking the JLC SMT parts catalog, they have the specific FPGA and STM32 chips and most RCL parts, but other ICs I will try a hot gun soldering after most passive parts assembled.

Would you please add a gerber folder and put the gerber files for the PCB? I have read previous talks about the stacking, and I will place the spec accordingly when I place the order.

Something else not sure about the BOM is the "100n, 0402, broadband capacitor (e.g. ATC 530L series: ATC 530104KT16T)". could I just use 50v MLCC from Samsung? (with JLC part# C1525), or any other suggestions or a mouser part# please. I can contact JLC with a specific part if available from mouser in China.

One more thing in this issue is the CNC closure, I can design a 3 parts assembly with a from panel to improve SMC socket grounding contact. Will this effort be worth it?

Thanks.

jankae, 2021-03-11:
Hi,
here are the Gerber files of the current hardware version:
[VNA_2021-03-11.zip](https://github.com/jankae/VNA2/files/6124636/VNA_2021-03-11.zip)
They are nearly identical with the "Second Prototype"-Version described [here](https://github.com/jankae/VNA2/blob/master/Documentation/DeveloperInfo/VersionsAndModifications.md) except that the known mistakes have been fixed (additional inductor at amplifier, pinout of DC jack corrected).

Also, this is the generated placement file and BOM which is required for the JLCPCB assembly process:
[VNA_JLCPCB_parts.zip](https://github.com/jankae/VNA2/files/6124642/VNA_JLCPCB_parts.zip)
Please note that I never used the assembly process with these files, you'll have to carefully check them (especially the rotation of components could be wrong).

> Something else not sure about the BOM is the "100n, 0402, broadband capacitor (e.g. ATC 530L series: ATC 530104KT16T)". could I just use 50v MLCC from Samsung?

That  should work as well. The capacitor I used is specifically specified for high frequencies (and subsequently really expensive) but I actually didn't notice any difference when I used ordinary 100n capacitors I had lying around.

> One more thing in this issue is the CNC closure, I can design a 3 parts assembly with a from panel to improve SMC socket grounding contact. Will this effort be worth it?

I am not sure. Some people reported issues with the contact of the SMA connector (e.g. [changes in the measurement data when applying pressure to it](https://github.com/jankae/VNA2/issues/2#issuecomment-732785132) or [improvement of isolation when adding RF gaskets between the connector and the enclosure](https://github.com/jankae/VNA2/issues/2#issuecomment-751925450)). So far, I couldn't replicate any of those, it might vary from sample to sample. As long as you make sure that you have good contact between the 3 parts of your assembly, I believe it can only improve grounding contact. Whether it is worth the effort you'll have to decide for yourself.

taskx6004, 2021-03-11:
Your response is much faster than I expected. I will start checking process and report back the progress.

The probe socket (SMA connector) grounding issue makes me thinking about a nice video from a youtuber, who replicated a [CERN designed open source voltage-meter](https://www.youtube.com/watch?v=D28uSzCs7-k&t=242s), where a fancy probe grouding was made, I will evaluate the design they used and hopefully bring back something might be useful.

jankae, 2021-04-17:
Just closing up some stale issues, did you manage to get it produced with the files? If everything worked, I'd like to close this as well

taskx6004, 2021-04-18:
Hi, some chips are currently waiting for delivery, sorry about the delay. You can close it now as you wish, please check this thread some time when I have further questions.

taskx6004, 2021-04-26:
Hello,
After waiting for the chip over 4 weeks still not located a complete source of BOM, meanwhile I had good look into the fundamentals of the design of a VNA, I needed a wider bandwidth for my application, so I get started to design a LO+Mixer+ADC board. I am sorry for abandoning my previous idea and your help.

This new board reuses most of the RF circuit from another open source VNA on github, I guess you would know it's from github.com/ttl. My plan is to begin from building a standalone Rx part, then look into Artix7 pcie driver, and a raspberry pi 4 or jetson nx backend to host the software part. I have almost finished the schematics, the final things needed for this rx board is locating a proper priced tcxo, power chips.

I am looking forward to discuss this receiver design in the forum of this project, when the schematic and BOM is finally finished.

Closed 2021-06-28.

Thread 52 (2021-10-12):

System dynamic range improvement

blackberryer, 2021-10-12:
In the end, it was only inspired by the nanovna V2 project. The dynamic range of the system can be improved by redesigning the directional bridge. The MMIC-based differential amplifier instead of the balun can reduce the cost and increase the SNR, so as to achieve a faster scanning rate. Simply use an BJT LNA, which is much cheaper than a broadband balun.
I am here to make suggestions, not sure if it is feasible in principle.

blackberryer, 2021-10-13:
I’m sorry for not being very clear, maybe it’s just my own guess. In fact, what I mean is that I want to make some modifications to the following circuit.
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
Converted into the following scheme:
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

zsellera, 2021-12-03:
No RF engineer here, but using such amps makes sense if:

1. want to match different impedances (buffer)
2. signal conditioning (amplification before the mixer stage)
3. single-ended to double-ended conversion, or vice-versa

Here the bridge provides a differential output, and the mixer offers a 50 ohm *differential* input, which is perfect for the bridge (as it offers the same output). The balun here may act as a filter for the common-mode component coming from the bridge (guess), but I don't know why is it needed - maybe @jankae can shed some light on it.

The nanovna v2 is a switch-porn, where the bridge's differential 50 ohm output must be matched to a single-ended 50-ohm line. The baluns seen on the original (open) v2.2 design seem to me bad design choice, probably driven by cost reasons only. Having a differential input amp there makes perfect sense.

The ADL5960 has those preamps there probably for all three reasons (impedance matching, preamp and SE to differential conversion).

blackberryer, 2021-12-18:
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

I tried this circuit, which is basically effective, but the AGC part of V2 version is not open source, resulting in the noise of more than 1G in my actual test, but the approximate track is correct. In addition, the author of V2 chose balun, which is unreasonable. He may not have seen jankae's design. If he has, the design of balun should be better

YuryW, 2022-06-12:
An improvement in the frequency dependence of the dynamic range of S11 and S22 (at the same time as S12 and S21) can be obtained by replacing two baluns at the meter ports in LibreVNA with wider ones, for example, MABA-011108 ( https://www.macom.com/products/product-detail/MABA-011108#part-tech-order   )  .
A further increase in the dynamic range of S12 and S21, in my opinion, is achieved by continuing to apply the already used idea - to install an additional QPC6324 between the switch and the ports themselves. Then the noise floor of S21 and S12 will be determined by the bandwidth and shielding of the individual LibreVNA nodes.

YuryW, 2022-11-03:
If we assume that the spurious signal penetrates through the paths indicated in the figure in red,
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
then I propose one of the solutions as follows. At the points marked in the figure,
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
as an example, put a 12dB attenuator and a TRF37A73 amplifier. S12 of such an amplifier decreases with increasing frequency and reaches -19...-21 dB at 4...6GHz. That is, if the assumption and paths of spurious signal penetration are correct, we will get an improvement in isolation between LibreVNA ports in the upper part of the range of at least 31 dB.
Or the second option is to put a separate MAX2871 synthesizer on each ADL5801 mixer.

YuryW, 2022-11-07:
Hi Slawek.
If we assume that LO-to-RF Input Leakage = RF-to-LO Input Leakage for ADL5801, then at 5500 MHz they are equal to 29 dB. A 25 dB resistive coupler has 0 dB isolation. The simulation showed that for a TCM1-63AX+ bridge with an input resistive attenuator, the reflected wave is at best 19 dB at 6 GHz. On two QPC6324 switches, 1.35*4=5.4dB will be lost in both directions. Then we get mathematically only along this path we have an isolation between the LibreVNA ports 19+5.4+0+29+29=82.4 dB with a calibrated load on port No. 1.

YuryW, 2023-01-10:
Good day everyone.
Assuming that the isolation in the ADL5801 LO -> RF is approximately equal to RF -> LO only at frequencies closer to 5...6 GHz, and at low frequencies RF -> LO is much less than LO-> RF, which is indicated in the datasheet approximately 29 dBc, then the problem of improving the dynamic range at high LibreVNA frequencies can still be solved by adding a 12 dB attenuator and a TRF37A73 amplifier before the LO inputs of the first mixer (see post on Nov 3, 2022 above). Indirectly, this is evidenced by the changes that the 6-layer version received and which, in my opinion, led to an improvement in the dynamic range compared to the previous version - namely, in the 6-layer version, a 10 dB attenuator appeared before the LO ADL5801 input (except Port 2) .

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

In the absence of a signal at the RF input of the ADL5801, it is probably enough to have the first local oscillator signal at the LO input ADL5801 and the HF Source signal reduced by about 70 dB to get an IF of about -70 dB at the mixer output.

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

**_And perhaps it is enough to put a chain of 12 dB attenuator and TRF37A73 amplifier just before the LO input of the ADL5801 reference receiver. And for Port 1 and Port 2, before the LO input of the ADL5801, install only 10 dB attenuators._**
Moreover, the frequency response of the dynamic range in the formula 25 + 29 (frequency) +10 +10 will determine the value of 29 dB in the current LibreVNA scheme, which will change quite strongly when the frequency changes up to 65 dB at low frequencies.
Best regards.

YuryW, 2023-01-11:
A little continuation. I do not have a 3D electromagnetic simulator, but in my opinion in the layout of the 6-layer LibreVNA printed circuit board there are several dangerous approaches (from the point of view of mutual interference through vias less than necessary at -100 dB) of the 1.Lo and HF Suorce signal lines. Points 1 and 4 are especially questionable. In my opinion, there are no restrictions to remove these lines with signals from each other (at points 1, 2, 3, 4) to the maximum possible distance in this case without changing the dimensions of the case.

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

To view the traditional gerber and exellon files, I used the wonderful program for CNC machine tools (manufacturing of simple printed circuit boards) GGEasy.

https://github.com/XRay3D/GERBER_X3/releases

Best regards.

Closed 2023-10-23.

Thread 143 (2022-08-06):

The LibreVNA application works in W7_64, but VNA itself does not.

YuryW, 2022-08-06:
### LibreVNA Version

LibreVNA Version (64 bit): 1.4.0-7f6b78992
OS: Windows 7 Version 6.1 (Build 7601: SP 1)
CPU Arch: x86_64

### Steps to reproduce

The LibreVNA device is connected to the computer. The system sees it as VNA. The LibreVNA application does not see the LibreVNA device.

### Expected behavior

The LibreVNA device is connected to the computer via USB-2.0. The Ready and Power LEDs glow green. Supply voltage 5.18 V, current consumption 0.58 A. The W7_64 system sees it as a VNA. Then the LibreVNA application turns on and an error window pops up.
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
EmbeddedFirmware-hw-rev-B-v1.4.0 is installed in the device on W10_64.
In W10_64 everything is fine.

### Extra information & Setup and Calibration files

Designation Rev. B_6L means the board is 6 layer?
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

### Confirming that you haven´t forgot to include configuration files (if applicable)

- [ ] Setup file
- [ ] Calibration file
- [ ] Touchstone file of measurements

jankae, 2022-08-06:
Easy question first:

> Designation Rev. B_6L means the board is 6 layer?

Yes, that is the "new" version of the LibreVNA. "New" because not much has changed. Just some minor layout adjustments which lowered the noise floor a bit above 3GHz and also improved return loss slightly. No huge improvements and electrically identical (apart from some passives).

> The LibreVNA application does not see the LibreVNA device.

I don't have any machine running W7 anymore, so unfortunately I can't test this. But it could be a missing driver. The LibreVNA uses a USB descriptor which should tell windows what driver to load. Maybe that is not working properly on W7?
You can always try to assign the driver yourself: Use [zadig](https://zadig.akeo.ie/) and select the WinUSB driver for the LibreVNA.

YuryW, 2022-08-06:
Thank you very much!!! Zadig helped. The application began to work with the LibreVNA device in W7_64 as well. True, W7_64 now does not recognize LibreVNA as VNA, but this is not important. ))
Now I have VNA itself, so I’ll ask questions here more than once over time ...
And we close the issue as resolved. I hope that it will help not only me.

YuryW, 2022-08-06:
And there will be no version for W7-32?

jankae, 2022-08-06:
It should be possible to compile the project for 32bit systems. Probably just a matter of setting up the github actions to do that as well. I didn't expect anyone still using 32bit, so I didn't bother so far.

YuryW, 2022-08-06:
> Я не ожидал, что кто-то все еще использует 32-битную версию, поэтому пока не беспокоился.

You (or me) can ask this as a separate question so that it can be seen by everyone who enters the questions. And to get an opinion, such as conduct a survey, how many users still use this system. It's just that I have one workplace for general work and there is a specific place for devices via USB on the old computer and it's still difficult to change it to a new one...))

Closed 2022-08-06.

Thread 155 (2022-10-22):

Axis Setup->X axis Power - Default max is 6 GdBm. Trimming the level label in the lower left corner on the left and right.

YuryW, 2022-10-22:
### LibreVNA Version

LibreVNA Version (64 bit): 1.5.0-alpha.1-796a8cb3f
OS: Windows 7 Version 6.1 (Build 7601: SP 1)
CPU Arch: x86_64

### Steps to reproduce

LbbreVNA application is running. The device is not connected.
Trace Display Area ->XY-plot->Axis Setup->X axis Power - Default max is 6 GdBm. Trimming the level label in the lower left corner on the left and right.
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
And also here. Axis setup -> X axis : after switching from Frequency (Power) to Time or Distance, you cannot switch back to Freqency (Power) without exiting this (Axis Setup) menu and re-entering.

### Expected behavior

Probably the default X-axis Power should be Minimum -40 dBm, Maximum 0 dBm. Or something close to the characteristics of the device.
Or rather, as specified in Preferences -> Power Sweep : -30 dBm...-10dBm.

### Extra information & Setup and Calibration files

No.

### Confirming that you haven´t forgot to include configuration files (if applicable)

- [ ] Setup file
- [ ] Calibration file
- [ ] Touchstone file of measurements

jankae, 2022-10-25:
Okay, several small things in this issue:

> Trace Display Area ->XY-plot->Axis Setup->X axis Power - Default max is 6 GdBm

- While in the axis setup dialog, no autoranging is performed. The selected settings are only applied once you close the dialog. This means that you will still see the old min/max values when switching from one X axis type to the other, even when autoranging is active
- When the x axis is displaying power, autoranging only supports the "fit traces" mode
- In your example there are no traces (or at least no traces with datapoints), so autoranging doesn't know what to do and just leaves the minimum/maximum as it was
- If you now add a trace, autoranging should work as intended and adjust your X axis settings

I have now improved this slightly. In case autoranging doesn't find any traces, it uses default min/max values instead of just leaving them as they are. The default min/max values depend on the X axis type (frequency/power). If a device is connected, its maximum/minimum supported values are used as the limits. If no device is connected, some hardcoded default values are used instead.

> Trimming the level label in the lower left corner on the left and right.

This bug was recently introduced when fixing some display issues for larger font sizes. Should be fixed now.

> Axis setup -> X axis : after switching from Frequency (Power) to Time or Distance, you cannot switch back to Freqency (Power) without exiting this (Axis Setup) menu and re-entering.

This one I can't replicate. I can switch between any X axis settings for any number of times without closing the dialog inbetween.

YuryW, 2022-10-25:
> In case autoranging doesn't find any traces, it uses default min/max values instead of just leaving them as they are.

Now in LibreVNA Version (64 bit): 1.5.0-alpha.1-2dd4edfae
a little wrong. When switching X axis to Power with no device connected, the X range is set to -100dBm ... 30dBm. And in Sweep type Power the default is -30dBm...-10dBm. That is, these settings are not synchronized?
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

jankae, 2022-10-25:
> That is, these settings are not synchronized?

No, they are not. They would be for autorange mode "use span", but I haven't implemented that yet for the X axis in power mode.

What you are getting are the default values when no device is connected.

YuryW, 2022-10-25:
> This one I can't replicate.
We switch in X axis from Frequency to Time, then again to Frequency. Here's what I have with the charts...
The frequency graph will already be different.
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

YuryW, 2022-10-25:
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

Thanks Jankae. It's clear.

jankae, 2022-10-25:
> We switch in X axis from Frequency to Time, then again to Frequency. Here's what I have with the charts...
The frequency graph will already be different.

The switch from frequency to time disables the Y axes, because the previously selected axis types are not available in the time domain. When you switch back to frequency, they are still disabled (the software doesn't store the previously selected type). If you select magnitude (for the primary Y axis) and phase (for the secondary Y axis), you should get the original frequency graph back.

YuryW, 2022-10-25:
It's clear. And here too, Jankey. Maybe when switching Sweep Frequency to Sweep Power, or change graphics to other ones automatically, or not change the frequency on the remaining graphs?
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

jankae, 2022-10-25:
Ah, I haven't tested that specific case. The graphs can switch the axis type automatically, if the trace data changes. It only works halfway for you, because your traces are empty (no device connected). If you have incoming data, the graphs would have switched to power. You can control the behavior in the settings:
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

YuryW, 2022-10-25:
It's clear. A lot of the behavior of the application depends on whether the device is connected...
Let's close these questions then...

jankae, 2022-10-25:
I'll increase tests without the device connected in the future. Your case is also special because the only cases you have on the graphs are empty. If they would contain some points (e.g. imported from a touchstone file), the graph behavior would probably be a bit more intuitive.

Closed 2022-10-25.

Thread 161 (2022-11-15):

When the scan range is changed, point parasitic changes in the dynamic range appear.

YuryW, 2022-11-15:
### LibreVNA Version

LibreVNA Version (64 bit): 1.5.0-alpha.1-a29c32355
OS: Windows 7 Version 6.1 (Build 7601: SP 1)
CPU Arch: x86_64

### Steps to reproduce

The application is launched with default settings.
The LibreVNA device is connected.
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
Change the number of points to 2001.
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
Change the minimum scan frequency to 500 MHz.
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
Clear parasitic bursts are visible on S21 (5 pieces) and S12 (so far 1 piece).
Now we change the upper scan frequency to 2.5 GHz.
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
We already get more than 10 spurious points on S21.
Reduce the IF bandwidth to 200 Hz. Almost the same spurious emissions appear on S12.
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

### Expected behavior

Is it possible to get rid of these impulse pickups in the program settings? Or do you need to change something in the software?

### Extra information & Setup and Calibration files

No.

jankae, 2022-11-16:
Thanks for the report, I get very similar spikes (actually also on S12 before changing the IF to 200Hz). Interestingly, there is some difference between the VNA sweep and the manual control dialog. For example:
Zero span sweep at 1.111GHz (the location of a spike):
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
Signal level of about -66dB (similar to the spike).
The same settings with manual control:
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
Much better S21 result of about -100dB.

This will need some more debugging to determine the cause of the spike (most likely: aliasing of other frequencies into the ADC), I'll get back to you when I have more results.

jankae, 2022-11-16:
Some more info, at least I determined the cause of (most) spikes: It is 1.LO feedthrough mixed with harmonics of the 2.LO in the second stage mixer. Here with the example for the spike at 1.111GHz:
1.IF = 62 MHz -> 1.LO = 1173MHz
2.IF = 250kHz -> 2.LO = 61.75MHz -> 19th harmonic = 1173.25MHz

The second mixer now sees a 1173MHz input and also has some content on its LO at 1173.25MHz -> output 250kHz which the ADC interprets as a valid signal.

Unfortunately, there isn't really anything I can do in the software about that. Here are your possible work-arounds:
1. Shift your 1.LO or 2.LO in the preferences:
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
This will not fix the problem but it will move the spikes to other frequencies. Could be a solution if you are only interested in a narrow frequency range and want to get rid of a spike in there.
2. Add a median filter to the traces. This will hide the spikes if they are narrow enough. But of course it would also hide actual narrow signals.
3. Add a lowpass to the 2.LO. The PCB already has the footprints for that but they are not populated:
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

jankae, 2022-11-16:
> And even with an IF width of 10 kHz, once every few seconds in the very upper part of the range, a rather significant spurious impulse (burst) S21 and S12 slips through. (On IF 5 kHz and 20 kHz too, but less often).

Could that peak be at 5.928GHz? If so, please check that the following option is enabled:
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

YuryW, 2022-11-16:
Good afternoon Jankae. Thanks for the thorough answer.

> The second mixer now sees a 1173MHz input and also has some content on its LO at 1173.25MHz -> output 250kHz which the ADC interprets as a valid signal.

It turns out that the excessive broadband of the second mixer is to blame?

> 3\. Add a lowpass to the 2.LO. The PCB already has the footprints for that but they are not populated:

This option suits me the best. That is, LPF (3 pieces) at 62 MHz should practically solve this problem?

> Could that peak be at 5.928GHz? If so, please check that the following option is enabled:

Yes, this option is enabled. I set the marker mark to the frequency of 5.928 GHz: spurious bursts (once in a few tens of seconds or more often) both at this frequency and above it (quite wide sometimes).
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

jankae, 2022-11-16:
> This option suits me the best. That is, LPF (3 pieces) at 62 MHz should practically solve this problem? Is the location of these filters the same on a 6-layer LibreVNA board?

Yes, if that LPF attenuates the high harmonics of the 2.LO, it should also reduce the spike amplitude significantly (probably all the way to the noise floor for most frequencies). There could still be spikes with other causes but this should take care of most of them. The component location has not changed in the 6-layer board.

> I set the marker mark to the frequency of 5.928 GHz: spurious bursts (once in a few tens of seconds or more often) both at this frequency and above it (quite wide sometimes).

Unfortunately this is something that I can't replicate. I have added an option to show the raw data from the VNA receivers and would like to look at your raw data coming in. Could you please use the latest GUI and perform the following steps?
1. Enable raw data capturing in the preferences:
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
After this, you will have eight additional live capture parameters available (RawPortXStageY[Ref]).
2. Create a new trace for each of these parameters (trace name isn't important, but you must select the correct parameter in the traces setup)
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
3. Stop the sweep when the peak is present
4. Export all eight raw data traces as .csv (with magnitude and phase) and attach that csv file

YuryW, 2022-11-16:
> 4\. Export all eight raw data traces as .csv (with magnitude and phase) and attach that csv file

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
[RawPortStage_1.csv](https://github.com/jankae/LibreVNA/files/10024154/RawPortStage_1.csv)
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
[RawPortStage.csv](https://github.com/jankae/LibreVNA/files/10024158/RawPortStage.csv)

jankae, 2022-11-16:
Thank you very much for all the data. There is something in there that can explain the spike, although I still have no satisfying overall explanation: Your reference signal is almost completely missing for two frequency points. Without a reference signal, all receivers essentially only see noise and you get about 0dB for all S-parameters.
Here as an example in one of the raw data traces:
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
Don't mind the large absolute dB values, what matters here is the drop of about 90dB at the frequencies of the spike. A bit of background on what happens if you enable "suppress invalid peaks":
- The 1.LO PLL has a limited frequency resolution, especially close to integer multiples of its reference frequency
- Depending on the frequency deviation and the selected IF bandwidth, the 2.IF might fall outside of the IF bandwidth, this would result in something like I am seeing in your raw data
- With "suppress invalid peaks" enabled, I calculate these problematic frequencies in the VNA and adjust the 2.LO to move the 2.IF back into the IF bandwidth

So far, I can think of two possible problems:
1. For some reason, this movement of the 2.LO does not happen for you. I think this is unlikely because it is entirely software based (and not a new feature, so it definitely is in the firmware you are running).
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
jankae, 2022-11-20:
I think I found a cleaner solution: get rid of the lookup table altogether and calculate the required shifts of the 2.LO right when they are needed. When I initially implemented the lookup table I thought it would save time but when shifting the 2.LO I have to wait for it to lock anyway. Any additional calculation before that isn't really that critical.

Another firmware to test: https://github.com/jankae/LibreVNA/actions/runs/3505746388 (no changes to the GUI, updating the firmware is enough)

By the way: thanks a lot for all the extensive tests/screenshots/data :)

YuryW, 2022-11-20:
> Another firmware to test: https://github.com/jankae/LibreVNA/actions/runs/3505746388 (no changes to the GUI, updating the firmware is enough)

It just worked out great. Thank you very much. There are small incomprehensibility for me (jumps in phase and amplitude). Circled them. Perhaps this is not important, but just in case, and suddenly it will help, if anything. I think that we can now safely close the issue.
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
[RawPortStage_20_4499ps_1MHz_6GHz_10Hz_new.csv](https://github.com/jankae/LibreVNA/files/10048980/RawPortStage_20_4499ps_1MHz_6GHz_10Hz_new.csv)
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
[RawPortStage_20_4499ps_5GHz_6GHz_10Hz_new.csv](https://github.com/jankae/LibreVNA/files/10048981/RawPortStage_20_4499ps_5GHz_6GHz_10Hz_new.csv)
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
Best regards.

jankae, 2022-11-20:
> But with this firmware, what are the restrictions on the number of points now?

Still the 4501 point limit (limited by the amount of RAM in the FPGA). But the GUI already includes a segmented sweep option which automatically splits the sweep into multiple smaller sweeps (on the hardware level). This is completely transparent for the user, the only thing you might notice is a short pause in the sweep when the next segment is set up in the hardware. With this feature enabled, the point limit is 65535 (and could also be increased but I don't think anyone needs more than that).

> I think that we can now safely close the issue.

Okay, I'll go ahead and close this.

YuryW, 2023-01-05:
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

Hi Jankae,
Designed the LP filter for 2.LO based on the PCB layout of 6 layers of LibreVNA. Used QucsStudio. In my opinion, I used QucsStudio to the maximum in order to take into account all the parasitic elements that distinguish the filter from the ideal one in this frequency range (it is in the upper right corner of the diagram). The 5.1 pF capacitor improves the dynamic range at 6 GHz by about 10 dB (until I started using it). Capacitors must be in parallel of two of a smaller value, and not one of a larger one, so that filtering (dynamic range) is better according to QucsStudio.

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

Who wants to repeat this filter - pay attention to the marking of the applied capacitors and inductances from Murata. With other capacitors and inductors, the frequency response will be different.
All harmonics above 700 MHz are filtered better than 100 dB.
Here are the manifestations of harmonics of the local oscillator without a 62 MHz filter (see above (earlier) in the text of this problem.

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

And here are new measurements with similar old settings already with LPF 62 MHz applied. At S21, part of the parasitic bursts noticeably decreased, especially above 1.2 GHz, but at IF 1 kHz at S12, their number seems to have increased. In theory, these bursts should no longer be above 700 MHz.

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

YuryW, 2023-01-05:
> The second mixer now sees a 1173MHz input

If Jankae doesn't mind, then here or (probably better there) on the forum, I will later consider the pros and cons of other filters that come after the first and second mixer using QucsStudio.
Best regards.

YuryW, 2023-01-08:
I will offer an easy to remember way to solve the problem, when in such a case - the initial data: VNA, Start frequency 500 MHz, end frequency 2.5 GHz, number of points 2001, IF bandwidth 100 Hz, spikes appear, as in the picture below:

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

You need to shift the initial scan frequency of the VNA up or down by 250 kHz (IF2). In the vast majority of cases, such a change is acceptable for measurements and is practically not noticeable. But there is an effect:

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

Whether this always works will be shown by the experience of dear readers of the topics discussed here on LibreVNA (a wonderful assistant for amateurs and radio professionals).
Post your results here.

YuryW, 2023-01-10:
VNA mode: start frequency 1 MHz, stop frequency 6 MHz - there are bursts.

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

VNA mode: start frequency 1.25 MHz (750kHz), stop frequency 6 MHz - no bursts.

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

Closed 2022-11-20.

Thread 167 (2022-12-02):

Add to the Matching Network menu the parallel defined in the touchstone file (s2p).

YuryW, 2022-12-02:
### Summary

Good day everyone.
Many manufacturers of L and C publish their s2p parameters (touchstone file). In this edition of the LibreVNA application (LibreVNA Version (64 bit): 1.5.0-alpha.2-35cdfa592), it is not possible to insert a parallel element into the matching circuit, specified by the touchstone file. Is it possible to change this? Add to the Matching Network menu the parallel defined in the touchstone file (s2p).
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

### Paths to implement it

No

### Extra information

No

jankae, 2022-12-02:
Should be possible but I can't find the required math right now. If you can point me to that, it should be straight forward to implement.

YuryW, 2022-12-02:
Good evening Jankae.
I'll try to formulate my logic. If I'm not mistaken, then perhaps it will help. We need to obtain conductivity in a similar way to the already familiar (judging by the result already implemented in LibreVNA) connection in parallel with the capacitance C. Among the conductivity parameters Ynn, we are interested in Y11 or Y22, since they are obtained by a short circuit on the opposite side of the four-pole, which is present when our four-pole is connected in parallel in the matching circuit.
Formulas for recalculating Y-parameters from S-parameters of a quadripole can be taken from here:
https://www.spectrum-soft.com/news/winter2001/conv_spar.shtm
D = ((1+S11)*(1+S22)-S12*S21)
y11 = ((1-S11)*(1+S22)+S12*S21) / D
y22 = ((1+S11)*(1-S22)+S12*S21) / D.
As a result, we will get a complex conductivity similar to the complex conductivity of capacitance C. And its integration into the DUT matching chain has already been worked out in LibreVNA. If complex resistance Z is required, then it is the opposite of complex conductivity Y. In any case, the correctness of the implemented algorithm can be checked in a simulator, for example, QucsStudio (https://dd6um.darc.de/QucsStudio/qucsstudio.html).
And further. So far, I'm unable to negotiate the DUT chain of the downloaded touchstone file when the LibreVNA device is not connected. Here are some screenshots.
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

Maybe I didn't read the manual carefully. I would like to have a clear algorithm of actions, and so that when changing the matching circuit, and after pressing OK in the Matching Network menu, the result would be immediately visible on the graphs.

jankae, 2022-12-02:
> I'll try to formulate my logic

Thanks, your math looks reasonable to me. I'll probably try myself at the implementation soon.

> So far, I'm unable to negotiate the DUT chain of the downloaded touchstone file when the LibreVNA device is not connected.

There is a bug in the de-embedding for the matching network, it tries to de-embed as many ports as the connected VNA has (or, in case of no connected VNA, 2 ports). You only have the de-embedding configured for one port, so you can only supply one trace. The crash happens, when the algorithm starts looking for the other traces (which it shouldn't need here). I am working on a solution.

> I would like to have a clear algorithm of actions, and so that when changing the matching circuit, and after pressing OK in the Matching Network menu, the result would be immediately visible on the graphs.

There are two different scenarios:
1. You are de-embedding incoming VNA data. This should already work as you described here (new data on graphs will use the changed matching network after you change it).
2. De-embedding already existing traces. This will not work in this way and I don't think that is likely to change. De-embedding already existing traces modifies the trace data itself. This is a non-reversible operation. Afterwards, the GUI has no knowledge of which traces have been de-embedded, so it can't adjust them if you change your de-embedding setup.

YuryW, 2022-12-03:
Good day.
For a simple user of the LibreVNA application, I will explain how the DUT negotiation of the previously saved touchstone file works now (with no LibreVNA device connected). LibreVNA Version (64 bit): 1.5.0-alpha.2-35cdfa592.
First, in the open Matching Network menu, you need to insert all the elements you need into the DUT matching circuit and enter their parameters.
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

Only after that import the touchstone file. Then a menu will appear with a suggestion for de-embedding imported tracks. Check the box for deembedding.
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

After that, on the graphs, we add the corresponding traces with checkmarks and they appear already taking into account the matching circuit.
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

With any changes in the matching circuit, all procedures must be repeated. Also, for this matching network, you can import other traces with their subsequent addition to the graphs.
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

Best regards.

YuryW, 2022-12-03:
Compared connecting a 1 nH inductor in series on port 1 in QucsStudio and LibreVNA. So far, the same result is not obtained after matching, although everything worked the same way before turning on the inductance.
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

jankae, 2022-12-03:
I also noticed a couple of other bugs in the matching network de-embedding. Mostly introduced by the recent changes for more flexible port arrangements. I'll fix them and do some more tests but it will take a couple of days, I am quite busy at the moment.

YuryW, 2022-12-06:
Good afternoon.
In LibreVNA Version (64 bit): 1.4.0-7f6b78992, not only matching network worked great, but it also had the ability to work on two ports at once. Is it possible to return all this again in the new edition? It will be easier and cooler, in my opinion. ))
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

jankae, 2022-12-06:
>  it also had the ability to work on two ports at once or with any of the ports separately, placing the elements just in the right places. Is it possible to return all this again in the new edition?

In 1.5.0 you can add multiple matching networks. If you add one for port 1 and one for port 2, this should give you the same options as in 1.4.0 (but of course you can't view both matching networks at the same time). This is more flexible because it allows for matching networks on any number of ports (1.4.0 was limited to two ports).

It also makes the calculations a bit more complicated (I am using ABCD-parameters internally for the matching network and haven't fully figured out yet how to concatenate networks with more than two ports). But once the bugs have been fixed, this should be working correctly just as in 1.4.0.

YuryW, 2022-12-06:
> (but of course you can't view both matching networks at the same time)
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
jankae, 2022-12-08:
> there is no possibility of matching on port 3.

The de-embedding options were limited to the number of ports on the connected device (or 2, if no device is connected). But your experiments show that it might be useful to allow higher port numbers as well when importing other data. The latest commit always allows the user to go up to port 8 for the de-embedding, regardless of whether a device is connected or not.

jankae, 2022-12-08:
> By the way, QucsStudio is not Qucs, so don't "offend" its creator ... ))

Ah, I wasn't aware that these are actually different projects. I found the user interface of Qucs a bit unintuitive when I last tried it, I might give QucsStudio a go

YuryW, 2022-12-08:
> I might give QucsStudio a go

"... QucsStudio is mainly a circuit simulator that has evolved out of the project [Qucs](http://qucs.sourceforge.net/), but isn't compatible with it. The simulation engine is even a complete new creation...."

Qucs is no more. There is a "low frequency" version, now called Qucs S (Spice) and a high frequency version that is very fancy, cool for free versions of QucsStudio.

YuryW, 2022-12-08:
> The latest commit always allows the user to go up to port 8 for the de-embedding, regardless of whether a device is connected or not.

If you do it in sequence - first matching networks in ports, then importing s3p and ticking de-embedding, then the calculation does not take into account the elements in port 3.
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

If further in the Manual De-embedding menu you select specific traces:
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

then we get this.
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

If you first import s3p, and then create matching networks for ports, then the calculation after OK in the De-embedding menu does not occur. And after selecting the traces in the Manual De-embedding menu, the calculation takes place without taking into account the elements in support 3.
And here is the result in QucsStudio:
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

[sXp.zip](https://github.com/jankae/LibreVNA/files/10190425/sXp.zip)

jankae, 2022-12-08:
> the calculation does not take into account the elements in port 3

Unable to reproduce. No matter in which order I do the de-embedding (set up the chain first then import or import first and de-embed later), I very clearly get results on all three ports:
Without any de-embedding:
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
After de-embedding:
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
The matching network is identical for all three ports:
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

YuryW, 2022-12-09:
And I have the same result.
But the transfer characteristics do not match with QucsStudio, and the reflection parameters seem to be close. Tweaked your test a bit to get away from very large values   in trace results.
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

Need to test more.

YuryW, 2022-12-09:
Yes, and I also noticed that if you don’t like the color on the de-embedding track and change it, then the track, after updating its color, is drawn, but in the form that it had before de-embedding.

jankae, 2022-12-09:
> But the transfer characteristics do not match with QucsStudio, and the reflection parameters seem to be close.

I think I figured it out now. Consider this matching network:
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
My internal S or ABCD parameters only support two port networks, so I perform two de-embedding calculations: One uses P1 and P3 of the DUT, the other P1 and P2 (P1 is calculated twice but the result is the same - no issue here it will just get overwritten with the same value again). But this doesn't change S32 and S23. I initially thought that was fine but there is actually another signal path now.
Example for a signal from P3 to P2:
This is transferred through S23, but also through
```
S13*Sxx*S21
```
where Sxx is the reflection from the DUT P1 at the matching network.
Sxx can be calculated as
```
Sxx = SM22/(1-SM22*S11)
```
where SM22 is the return loss of the matching network at the DUT.

So S23 actually also needs to be updated when de-embedding:
```
S23 = S23 + S13*SM22/(1-SM22*S11)*S21
```

With these changes added to the code I now get identical results as in QucsStudio (I imported the de-embedded S parameters from QucsStudio, they match my calculated traces exactly).

YuryW, 2022-12-09:
In my test, too, everything coincides perfectly with QucsStudio.
(Well, QucsStudio has already come in handy).

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

But in such a test (LibreVNA Version (64 bit): 1.5.0-alpha.2-b67275831) : s2p import and parallel inductance 1 nH on both ports, everything is the same as before.

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

dna35, 2022-12-10:
Impressed!

jankae, 2022-12-10:
Okay, looks like this finally works as intended. Thank you for all the help with the debugging :)
If you find no further problems, I propose to close this issue now (the resetting trace when changing the color is unrelated. I am already on it, but you can also open a new issue for that if you want)

Closed 2022-12-10.

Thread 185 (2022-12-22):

Graph does not reset amplitude until 1st overwrite

dna35, 2022-12-22:
### LibreVNA Version

LibreVNA Version (64 bit): 1.5.0-alpha.2-77dfabc67
OS: Windows 10 Version 2009
CPU Arch: x86_64

### Steps to reproduce

When changing a slow scanning graph, the amplitude overwrites as it scans. For a slow RBW of 100 Hz, it will look unusual.

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
Fig. 1 The red and blue lines are dropping down from the previous "Y" axis values.

If the red and blue are paused, it will take a full cycle of the red & blue un-paused to clear the graph of the vectors.
However, in this instance with the averaging on, it will require more than one sweep.

### Expected behavior

Reset amplitude to the starting point of trace if beginning a new trace.

### Extra information & Setup and Calibration files

None

jankae, 2022-12-22:
This issue is unclear to me. In particular, I do not understand what you mean by "reset amplitude". Does this refer to deleting/clearing old trace data? Or do you mean something related to the autoscaling of the Y-axis (amplitude)?

The trace should reset (get cleared) when:
- Sweep settings are changed
- A new device is connected
...essentially whenever new sweep settings are transferred to a device.

The trace should **not** reset (get cleared) when:
- if you pause/un-pause a trace, as this does not reconfigure the VNA. It simply ignores new incoming data for the paused trace

dna35, 2022-12-22:
> * if you pause/un-pause a trace, as this does not reconfigure the VNA. It simply ignores new incoming data for the paused trace

Yes, this would typically be an acceptable case, but when the RBW is extremely low, averaging is used, graphs are paused and restarted then the graph clutter builds up. I'm just showing what I see from a user point of view.

jankae, 2022-12-22:
In my opinion that is exactly the purpose of the pause: You can freeze data and look at it while the actual measurement might change. I understand that an argument could be made for resetting the trace when it is un-paused. However, this wouldn't get you new data faster - it would just not show the old data anymore.

But since you, the user, know that you paused the trace, you also kwow that it still contains old data. And maybe you even want to see that old data (e.g. to observe changes in the measurement). As of now, I am not convinced that un-pausing a trace should clear all prior trace data.

dna35, 2022-12-22:
I agree with your assessment, that's why making this case is difficult.

jankae, 2022-12-22:
> The point is to not have the trace drop down as a vector while it plots the current trace after the "Y" axis is changed.

Okay, I need a step by step guide for that. I still don't understand at what point you change the Y axis. If you have a "hole" in your trace (e.g. values from 1-2 GHz and from 4-5 GHz), the last point before the hole (at 2 GHz) will be connected to the first point after the hole (at 4 GHz) with a straight line. The trace doesn't really support a concept of multiple disjointed sub-traces.

You could achieve such a hole by pausing/un-pausing a slow sweeping trace. Is that what you are referring to?

dna35, 2022-12-22:
The scenario is this:

AT 100Hz RBW and no noise source attached, the ambient noise level is below -121dBM. When the noise source is attached but not activated, the noise increases slightly. When the noise is turned on after going through a 30dB amplifier, the noise increases by 10dBm.

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
Fig.2 This is similar after pausing and starting

The difference between Fig.1 and Fig. 2:

Fig.2 shows pausing and starting the traces which is the typical behavior I'm aware of, but in the extreme case of Fig, 1 there must have been data from a "Y" value that differed greatly.

At the moment this may be a moot point and we can move on.

dna35, 2022-12-22:
Changing to the flat top filter is the most likely change in "Y" value but this is not a bug.

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
Fig. 3

dna35, 2022-12-22:
If there are no further comments, I will close this issue as a non-bug.
Thank you for your assistance, Jan!

Closed 2022-12-22.

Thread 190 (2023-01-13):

Command via SCPI: Timing & Temperature Problem

rainermueller77, 2023-01-13:
### LibreVNA Version

LibreVNA Version (64 bit): 1.4.0-7f6b78992
OS: Windows 10 Version 2009
CPU Arch: x86_64

### Steps to reproduce

- Load attached Setup (S21, 1 - 3 GHz, 1601 points, 1kHz)
- Control LibreVNA over SCPI commands
- Do single sweeps and read data in a loop (see command list below)
--------------------------------------------------------------------------------------------
//Configure LibreVNA for single sweeps
:DEV:MODE VNA
:VNA:SWEEP FREQUENCY
:VNA:STIM:LVL -10
:VNA:ACQ:AVG 1

//Sweep Parameter
:VNA:FREQuency:START 1000000000
:VNA:FREQuency:STOP 3000000000
:VNA:ACQ:POINTS 1601
:VNA:ACQ:IFBW 1000

//Do 2400 sweeps
for (i=0, i++, i<2400){
   // Sweep ausführen
   :VNA:ACQ:SINGLE TRUE  // start a single sweep
   Sleep(400)
   do {
      :VNA:ACQ:FIN?
      Sleep(50);
      read_data(&SocketID, ReadString);
      Sleep(50);
   } while (strncmp("TRUE", ReadString,2)==0);
  // Trace auslesen
  :VNA:TRAC:DATA?
  Sleep(50);
  read_data(&SocketID, ReadString);
}

### Expected behavior

ISSUE 1:
After command a single sweep (:VNA:ACQ:SINGLE TRUE) sometimes it can take up to 400ms until the answer of :VNA:ACQ:FIN? switches to FALSE. Typically it takes less than 100ms. It should switch to FALSE immidiatelly after sending the sweep command

ISSUE 2:
The temperature seems to become very high (until the device crashes) when doing single sweeps compared to contimous sweeping.
Using the programm below the temperature rises over 90°C within less than 2 hours (see picture). When the LibreVNA just loads the attached setup and is running in the continous sweep mode with the same parameters the temperature stays below 50°C.

### Extra information & Setup and Calibration files

Setup file and picture
[S21setup.zip](https://github.com/jankae/LibreVNA/files/10412022/S21setup.zip)
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

jankae, 2023-01-13:
> LibreVNA Version (64 bit): 1.4.0-7f6b78992

Can you please check with the latest version? I know that it isn't released yet but I am fairly sure that this problem

> It should switch to FALSE immidiatelly after sending the sweep command

has been fixed in the meantime. I can't find the commit right now but I do have a testcase for that exact scenario in my integration tests and it passes.

> The temperature seems to become very high (until the device crashes) when doing single sweeps compared to contimous sweeping.
Using the programm below the temperature rises over 90°C within less than 2 hours (see picture).

Have you verified the temperature by touching the device? (maybe not directly if it is actually that hot). But I am fairly certain that this is a temperature read-out bug. There is no way the PLLs are up to 95 while the MCU is still at 34. Again, I'd like you to try with the latest version and verify the bug. There have been close to 200 commits since the version you are using.

rainermueller77, 2023-01-14:
I checked with the latest version. Issue 1 is fixed! I also couldn't reproduce issue 2, so I assume it is fixed.
But I got another strange behavior:

After a couple of 1000s sweeps, sometimes not all frequency points are measured. With the settings from above all frequency points between 1 GHz and 1.1 GHz are missing which leads to less measured points when reading via SCPI. In the LibreVNAGUI I can also see that the missing points were not measured.

I implemented a work around:
- Check the number of frequency points
- If  number is less then expected, do another sweep and read again.

Closed 2023-10-23.

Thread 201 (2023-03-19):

Poor lines

Chorbu, 2023-03-19:
### LibreVNA Version

LibreVNA Version (64 bit): 1.5.0-alpha.2-54de9fd6b
OS: Windows 10 Version 2009
CPU Arch: x86_64

### Steps to reproduce

Since a few months i have strange traces with a lot of non linearity traces. Calibration is OK,.
Il tryed to change USB cable, and try it on another PC : Same thing happened
My hamradios are off (VHF and UHF) , no spurious emissions near the VNA.
I tried to change IF1 and IF2 but without result,
Actual values are

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

I also put a good power supply by connect a DC power supply >2A (same result)

I hope this is not due to a degradation of components inside VNA.

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

### Expected behavior

What do you think about that ?

Could you give me original values of IF1 and IF2 ?

### Extra information & Setup and Calibration files

no extra information

jankae, 2023-03-19:
Hm, looks strange. Your IF values are at the default. Can you please try older firmware/GUI versions to determine whether this is a hardware or software problem? You can also enable "capture raw receiver values" in the preferences (either under Debug or LibreVNAUSBDriver, depending on your GUI version). This gives you the option to create traces from just the port or reference receiver instead of Sxy. That might get us additional insight about the source of these spikes/noise.

Chorbu, 2023-03-19:
I 've just try this software and firmware (before is not possible)
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

Same issue....

jankae, 2023-03-19:
Okay, I think that rules out the possibility of a new bug, I think other people would have noticed and notified me by now if that was the case.

Please look into the raw receiver values. Another thing you could try it starting the manual control dialog, enabling all PLLs and the amplifier and take a screenshot of that. On its own this is probably not that helpful but if I compare it to my LibreVNAs we might see that some values are off/different.

Chorbu, 2023-03-19:
Here is the screenshot of Manual control dialog
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

I activate Capture RAW receiver but i don't know where the values are saved...

Chorbu, 2023-03-19:
i forgot to activate Amplifier...

Chorbu, 2023-03-19:
But same issue

jankae, 2023-03-19:
> I activate Capture RAW receiver but i don't know where the values are saved...

You can change a trace to use the raw receiver value here:
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
All parameters except for RawPort1Stage1Ref and RawPort2Stage0Ref would be interesting to me.

> But same issue

Can you please post a screenshot of the manual control dialog with the amplifier enabled? The ADC values should get much larger.

Chorbu, 2023-03-19:
OK thank you

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

jankae, 2023-03-19:
I assume you still have something connected to the ports? Otherwise the port 2 ADC values are much too high. But otherwise that looks good. This is from my device:
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

Chorbu, 2023-03-19:
Here all the screens for RAW
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

Chorbu, 2023-03-19:
I i have a band stop filter 144MHz to 148MHz connected to my VNA

Chorbu, 2023-03-19:
So I'm going to stop it for tonight, tomorrow work and up at 6am.

Thank you in advance Jan, good night to you too.
Patrick

Chorbu, 2023-03-19:
Oh i ve just see you've already add APPLY button for my previous request !!!! Thank you for your extreme speed !!!!

Good night
Patrick F5SUE

jankae, 2023-03-19:
You raw receiver data doesn't reveal any obvious issues (maybe a bit too much noise on the reference receiver data, but your problematic signals are coming from the port receivers). Just to make sure that it isn't from the DUT: what happens if you change the setup? (e.g. just measuring a direct through).

You can also try to reduce your IF bandwidth. Some narrow band filters have quite the long settling time and might not have fully settled in the time the VNA takes to measure a point for higher IF bandwidths. That could easily result in the measurement data you are getting.

Chorbu, 2023-03-19:
With 500Hz IF BW or more is the same issue. Tomorow evening i will try again my other filters, splitter, coupler etc...

Chorbu, 2023-03-19:
THRU connected (I SMA) after calibration

S12 is Magnitude
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

jankae, 2023-03-19:
Yeah, that is too much noise on the reference receiver. Same settings on my VNA:
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
I am unsure why you are getting that. Let's both sleep on it, maybe there are new ideas tomorrow.

Chorbu, 2023-03-19:
Yes i saw that !!! Ther is a problem with my receive port !

Chorbu, 2023-03-19:
Thank you Jan, thanks for your help. Have a good night
Patrick

Chorbu, 2023-03-21:
Hello Jan,

The BandPass filter is REACTEL Fcenter 2150 MHz  réf SN86-1 (surely from an old SNA i supposed).

Here are the test comparaison with an ARINST VNA (without calibration made).
You can see behind the stop band filter for 2m fréquency

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

Bests Regards
Patrick

Chorbu, 2023-03-21:
Jan,
Here 2150 Bp Filter with the LibreVNA spectrum analiser with tracking

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

And Here the 2m Stop band filter with my old HP8568B analyser with HP8444A tracking generator

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

jankae, 2023-03-22:
Okay, did you check it with 10 Hz IF bandwidth as well? Just to rule out the settling time issue I mentioned.

Chorbu, 2023-03-22:
Hi Jan,

I've just made the test with 10 Hz IF BW and it seems good with the 2150 MHz bandPass filter.

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

I will try with the 2m stop band filter.

Chorbu, 2023-03-22:
Same with 40 Hz IF BW

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

Chorbu, 2023-03-22:
So it works well under30 Hz IF BW, so i think you can close this PR.

Many thanks, have a good evening.
Patrick

jankae, 2023-03-22:
Okay, thanks for all the additional measurements. Some background information on the "problem", because you might notice that other VNAs can work at higher IF bandwidths: what matters is the overall time after which the stimulus signal is stable. If there is a sufficient delay before sampling the ADCs, you can also take measurements at much higher IF bandwidths. Some VNAs also have a special mode to introduce additional delay there. The LibreVNA currently has no option for any delay (apart from the fixed delay due to the locking of the PLLs) and it is also optimized for fast sweep speed.

Selecting a lower IF bandwidth has a similar effect because more ADC samples are needed (which takes more time). As long as most of the samples are taken when the DUT has fully settled, you will get valid results. Otherwise you could end up with very noisy data - sometimes only in some frequency bands.

I'll go ahead and close this now.

Closed 2023-03-22.

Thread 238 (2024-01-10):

GUI Window cannot connect to LibreVNA

hungmks, 2024-01-10:
### LibreVNA Version

LibreVNA Version (64 bit): 1.5.0-07c2b8961
OS: Windows 10

### Steps to reproduce

When the first time I connect the LibreVNA, a notification appears for warning to update the new firmware version.
However, an error occurred during firmware updating, the GUI program closed suddenly.
After that, I try connect to LibreVNA again but I cannot connect device any more.
There is only the Power LED, the Booting LED isn't light.

### Expected behavior

Please let me know how to recover or upgrade firmware in case of cannot connect to LibreVNA GUI.

### Extra information & Setup and Calibration files

I have try to use some GUI version 1.2.0; 1.3.0; 1.4.0; 1.5.0 but still cannot connect to device.
There is an error in booting process due to error firmware updating, please let me know how to fix it.

jankae, 2024-01-10:
Hi, sorry to hear that.

Just to confirm: when you apply power to the LibreVNA only the power LED lights up and no other LED shows any sign of life? That is not good.

> However, an error occurred during firmware updating, the GUI program closed suddenly.

Do you remember the error message? Are you sure that the LibreVNA was powered by a sufficiently strong power supply during the update? As far as I know a power failure is the only way to really mess up the firmware update. If the power supply fails late in the firmware update process, the flash memory in the MCU might get corrupted (earlier in the firmware update process only an external memory chip is erased/written to and errors during that phase are recoverable over USB).

If you can not detect your LibreVNA through USB anymore (please also check in device manager, not just the LibreVNA-GUI), there is no way of updating/restoring the firmware again without opening the device.

You can restore the firmware by flashing the MCU through its SWD interface. For that you need an ST-Link programmer. Here is what you need to do:

1. Remove the aluminum housing of the LibreVNA
2. Apply power
3. (optional but could help detect other issues): there are labelled voltage test points on the bottom side of the PCB. Verify that +1.8V and +3.3V are present. The 6V and 5V test points should also have a voltage on them but it may be a bit low if the firmware is not running
4. Attach the ST-Link to these pads:
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
5. Flash the MCU firmware. You can use the [STM32 ST-Link utility](https://www.st.com/en/development-tools/stsw-link004.html) for that. This is the latest hex file for the MCU (rename to .hex, Github doesn't allow that file ending for attachments):
[VNA_embedded.txt](https://github.com/jankae/LibreVNA/files/13885350/VNA_embedded.txt)
6. The LibreVNA should show signs of life again (boot LED blinking) but it is still missing the FPGA bitstream and will not fully boot
7. Use the GUI and connect to the LibreVNA (should get detected but due to the missing FPGA configuration no measurements will work)
8. Update the firmware through the GUI, this writes the FPGA bitstream again. Afterwards you should have a fully working LibreVNA again

Best of luck, let me know if you get stuck at some point and sorry again that you have this far from ideal experience. If you can replicate the problem or provide more details on the exact error message/crash I can try to add a bugfix. But at the moment I don't really know what went wrong.

hungmks, 2024-01-11:
Thank you so much for your quickly reply.
Yes, when I apply power to the LibreVNA device, there is only power LED lights up no any other LEDs.

I only remembered that the Windows display for firmware upgrade still shown "rebooting..." and suddenly closed all.
It maybe that the LibreVNA didn't apply a strong power supply. Because I thought that the USB-PC connection had supplied power enough :(.

I will try to restore firmware of MCU by using the ST-Link programmer via SWD interface as your instruction.
The issue status will be updated after I fix it.
Thank you!

hungmks, 2024-01-16:
Hi Jankae,

When I try to flash the MCU firmware, I faces on the error like as the picture.
I have a question, should I have to erase full chip before loading MCU firmware?
Thank you.
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

hungmks, 2024-01-16:
I have fixed this issue.
I have confused in .bin file and .hex file, after I loaded the .hex file for flashing MCU firmware.
Now, the LibreVNA is working well.
Thank you so much for your support.

jankae, 2024-01-16:
Thanks for update, glad you got it working again :)

Closed 2024-01-16.

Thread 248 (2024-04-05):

Make SCPI interface more standard

scott-guthridge, 2024-04-05:
### Summary

On my bench, I have several devices connected by GPIB (IEEE488) behind a National Instruments GPIB/ENET adapter.  I also have a Tek scope that implements a SCPI interface through a TCP/IP socket.  I have quite a few existing programs I use for automation.  I found, though, that when using an existing program as a template for the LibreVNA, I had to make a lot more changes than usual when going between devices because the LibreVNA's SCPI interface deviates the most from standard SCPI semantics.

The usual flow for an automation program is first to send a lot of commands to set up the instrument.  In this example, the Tek scope over TCP.  [This example, interestingly, implements a low-frequency VNA using the scope to measure amplitude and phase difference vs. the reference signal.]

```C
    fprintf(fp, "\n*CLS\n");     /* clear any past errors */
    fprintf(fp, "DESE 60\n");   /* CME|EXE|DDE|QYE */
    fprintf(fp, "HEADer OFF\n");
    fprintf(fp, "VERBose OFF\n");
    fprintf(fp, "SOCKETServer:PROTOCol NONe\n");
    fprintf(fp, "ACQUIRE:STATE OFF\n");
    if (a_opt == 1) {
        fprintf(fp, "ACQUIRE:MODE SAMPLE\n");
    } else {
        fprintf(fp, "ACQUIRE:MODE AVERAGE\n");
        fprintf(fp, "ACQUIRE:NUMAVG %d\n", a_opt);
    }
    fprintf(fp, "ACQUIRE:STOPAFTER SEQUENCE\n");
    ... etc. ...
```

In this case, we sent sent 40 or 41 back-to-back commands (depending on the if/else above).

Next, check if anything so far generated an error:
```
    fprintf(fp, "*ESR?\n");
    fflush(fp);
    if (fgets(buffer, MAX_LINE, fp) == NULL)
        ... handle socket error ...
    status = atoi(buffer)  // actually, I use strtol and test that a numeric reply was really returned
    if (status != 0)
        ... handle error ....
```

The standard event status register bits are defined as:

    7  PON   device was powered on
    6  URQ   user request (can mean someone tried to push a button on the front-panel when locked out)
    5  CME   command error
    4  EXE   execution error
    3  DDE   device-dependent error
    2  QYE   query error
    1  RQC   device wants to become the controller (of the bus)
    0  OPC   operation complete  (works in conjunction with *OPC)

Not all of these bits make sense for the LibreVNA.  For example, it's not clear that the GUI knows when the device was powered on, so PON may not make sense to ever set.  Maybe there is no need for URQ.  On the other hand, the CME bit (syntax error in command) definitely makes sense.  Clearly, RQC doesn't apply.  OPC can be implemented for completeness, described further below.

If no errors, we trigger an acquisition and wait for the acquisition to complete.

```
    fprintf(fp, "ACQUIRE:STATE ON\n");
    fprintf(fp, "*WAI\n");
```

The *WAI blocks command processing until the background acquisition we triggered completes.  We need to synchronize with the acquisition because the next command we're going to send is a query to grab the acquired data, and we need to make sure the data is going to be there when we ask for it.

There are several alternatives to the *WAI command.  A very similar command is *OPC?.  The only difference between *WAI and *OPC? is that the former doesn't print any output while the later prints a "1" on a line by itself.  Programmer will usually use *WAI followed immediately by a :DATA...? or :CURVE...? if all they want is the data back.  They'll use the *OPC? method if they need to do some action in the program in response to the asynchronous command completing, for example, tell another device to do something. It's also possible to use OPC (which doesn't block command processing -- just arms a mechanism to set the OPC status flag next time all async events have completed) followed by either polling the OPC flag in the event status register, or causing the device to generate a "service request" to generate an interrupt on the host (which could be implemented over TCP/IP by sending an "urgent" message on the socket).  In real IEEE 488, there is also serial poll and parallel poll, but those require having a control channel separate from the data channel [NI GPIB-ENET and Visa interfaces implement this by using multiple socket connections].  Of of all these, probably *WAI and *OPC? are the most useful when working with a single device over a single socket.

Finally, once we know the acquisition is complete, we can ask for the data:

```
    fprintf(fp, "DATA:....?\n");
    .... read the data back ...
```

In another issue, a comment mentioned that the *OPC? command was interpreted to just wait for the previous command and not wait for asynchronous actions triggered by that command.  That's not correct, though.  The main purpose of *WAI and *OPC? are to wait for asynchronous commands, usually acquisition commands, to make data available.  If the previous command's effect were synchronous (as opposed to triggering something), then of course it's finished when we get to this command.  We could equally have just sent *IDN?  in this case since it doesn't really wait for anything.  That isn't a very useful semantic for *WAI/*OPC?

There was also a question about what to do if acquisition averaging or continuous acquisition is enabled.  Those semantics are well-defined in SCPI.  In the averaging case, the operation should be considered complete after the specified number of acquisitions have been taken.  In the continuous case, the operation should be considered complete when the next acquisition completes.  In all of these, the main completion criterion is: when can the user send a :DATA....? command and be guaranteed there will be new output available.

The LibreVNA SCPI interface would be more useful and easier to adapt to if it didn't print responses to non-query commands, implemented *WAI and *OPC? to wait for acquisition complete / data available, and provided a basic implementation of the standard event status register and its related commands, at least: DESE, DESE?, *ESR?, and if possible, the others: ESE, ESE?, *STB?, *SRE and *SRE? for adherence and completeness.  In the next section, I give suggestions on how to do this in a way that doesn't break existing compatibility.
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
scott-guthridge, 2024-04-16:
After an *RST command, the device goes into VNA continuous sweep mode.  But section 10 "*RST Conditions" of the SCPI standard says that devices should not source power from any port after an *RST.  This actually makes sense.  Suppose, we're doing several automated tests on some delicate device.  Each test would like to start out with a *RST to clean up any settings from the previous test, then set whatever is needed for this test, e.g. in this case, `VNA:STIMulus:LVL -30`, then run the test.  Shutting off outputs protects the device from possibly strong signals while the setup is being done.   So, I think *RST should reset all settings as it's doing except that it should also turn off sweeps.

Status: I'm working on minimal modifications to the existing tests to make them work again.  Then I'll build on that and add more tests in a few small commits.  Should I open PRs for each incremental change?  I'm currently chasing a problem with output of the next query sometimes getting eaten after a :DEV:CONN.

I have a lot going on, but am making steady progress.

scott-guthridge, 2024-04-16:
I would vote for the *RST command going to a fixed state, ignoring user preferences.  If it loads preferences, then automation scripts depend on external settings rather than being self-contained.  A seemingly innocuous change to a setting may change the behavior of existing programs.

SCPI also makes this statement: `Finally, thought should be given to implementing *RST conditions so that the incremental
programming necessary after *RST for the applications be minimized.`  They're suggesting that scripts shouldn't have to go through the gamut of setting every possible parameter to get into a known state.

One last argument I'll give is from the perspective of software compatibility.  Suppose an automation script does set every possible parameter to get to a known state, but later, a new parameter is added to the device that didn't exist at the time the script was written.  And suppose that the previous test run used the new parameter and didn't set it back to the default state.  Now the behavior of the existing script may change unexpectedly because it didn't know to set that new parameter back to the default.  Having *RST reset all settings avoids this type of inter-dependency.

All that said, I'm not suggesting changing the power-on behavior, but only the behavior of the newly added *RST command.

jankae, 2024-04-20:
Thanks for all the additional integration tests. And I agree, it is probably best to separate *RST from user preferences. I will come up with a solution for that

scott-guthridge, 2024-04-24:
Random thought: you might keep the *SRE, *SRE? and *STB?  commands unimplemented for now to leave open the possibility of using them later to implement a form of 'service request'.  In IEEE 488, any device can pull down on a control line to generate an interrupt on the host (solicited or not), then there are a couple different protocols the host uses to figure out which device it was and what it wants, using an out-of-band protocol to retrieve the status byte (SBR, not SESR) from the device -- it's done in a way that doesn't use or affect the normal command/response stream.  You can implement something over TCP that while isn't exactly the 488 service request, has the same spirit.  When service requests are enabled on the device (through *SRE), the device could signal to the host by sending an urgent/out-of-band message on the socket (sending the status byte (SBR) would be appropriate).  Device might send it again any time a bit has an inactive to active edge under the mask (status_byte & statsRequestEnableRegister).  Host software can select on the socket or have the OS send a SIGURG signal to notify it of the OOB, and read the OOB message to get the status byte.  Then it can interrogate the device as needed for more details.  Not only can this used to indicate completion of an async command, but it can also be used for reporting unsolicited conditions, for example, temperature/voltage over limit.  Bits 7 and 3-0 of the status byte can be used to indicate these kinds of conditions.  SCPI makes some recommendations for assignment of the bits: 7 for "operational status", 3 for "questionable status', 2 for "error event queued" and 1 and 0 free to the designer.  It gives some examples of events that would fall into those categories.  Anyway, an idea.

jankae, 2024-05-01:
I have changed the behavior for *RST to use fixed values now (regardless of the user preferences). Apart from the unimplemented SRE/STB, I believe with that all the requirements for making SCPI more standard are now fulfilled

scott-guthridge, 2024-05-04:
It looks great.  Thanks much for doing this.

Closed 2024-05-04.

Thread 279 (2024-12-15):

:DEV:INF:TEMP? query does not seem to work

scott-guthridge, 2024-12-15:
### LibreVNA Version

LibreVNA Version (64 bit): 1.6.1-f2b01f71c
OS: Fedora Linux 38 (Workstation Edition)
CPU Arch: x86_64

### Steps to reproduce

- LibreVNA-GUI --no-gui -p 12345 &
- Run the following script:

```
#!/usr/bin/env python3
from libreVNA import libreVNA

vna = libreVNA('localhost', 12345)
print(vna.query("*IDN?"))
print(vna.query(":DEV:INF:TEMP?"))
```

### Expected behavior

Last line printed should be something like: 45/51/31
But instead, it's giving a command time-out error.

### Extra information & Setup and Calibration files

n/a

jankae, 2024-12-15:
Thanks for the report, I accidentally dropped that functionality a while ago and didn't catch it yet.

Some background on what happened:
Initially, the USB protocol to the LibreVNA was very tightly integrated into the GUI. It still is part of the GUI, but I created a well defined interface layer abstracting the physical device. This has the benefit of being able to implement different device drivers, allowing the GUI to interact with other devices than the standard LibreVNA. These benefits have not really been utilized a lot so far, but I felt like this interface layer could come in very handy in the future.
But it also means that the more device specific commands (like reading the temperature) can not be implemented in the main GUI logic (because not every potential device will support them). Looks like I simply commented them out and then forgot about some of these lesser used commands. I'll see if I can come up with a way to implement device specific commands in the device driver itself.

jankae, 2024-12-15:
DEV:INF:TEMP? is working again with e848278.

I have added device driver specific commands and also took that opportunity to include the manual control commands as well (they were available for some older GUI version but never documented).

DEV:INF:TEMP? is now also added to the automatic tests to prevent me from forgetting about it again.

scott-guthridge, 2024-12-15:
Nice, thanks.  After posting, I looked at the code and saw that the implementation of the command was commented out.  The layering explanation makes sense.

Let me explain why I'm interested in this.  I've been doing experiments to explore various sources of uncertainty in calibration measurements.  I had looked at standard deviation of many measurements back-to-back with both reflect and match standards, and also tried to measure connection non-repeatability.  But it wasn't until I did a long time series that I noticed a source of error much larger than the others:

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

Here, I ran continuous measurements of a short standard on the end of 12 inches of RG-316 for about 27 hours.  VNA hadn't been acquiring before the start and was relatively cool.  It took over an hour for the initial ramp to flatten out.   The step starting at 4am correlates with the time the heat comes on in the house.  I don't show it here, but that step repeated at the same time over the next couple days, though not as sharpy.  I speculate that this was because outdoor temperature was warmer.

I'm wondering if I can compensate for these by taking the chip temperatures into account.

scott-guthridge, 2024-12-16:
Tested latest: works now, thanks.

jankae, 2024-12-16:
>  But it wasn't until I did a long time series that I noticed a source of error much larger than the others

Thank you for that chart/measurement. I'd love to know what the major sources for the temperature drift are (likely the 1st stage mixer but the 2nd stage mixer and ADC amplifier could also contribute something). It might be worth to add temperature control in a new hardware version (add heating resistors to temperature sensitive parts and keep them at the same temperature).

Closed 2024-12-16.

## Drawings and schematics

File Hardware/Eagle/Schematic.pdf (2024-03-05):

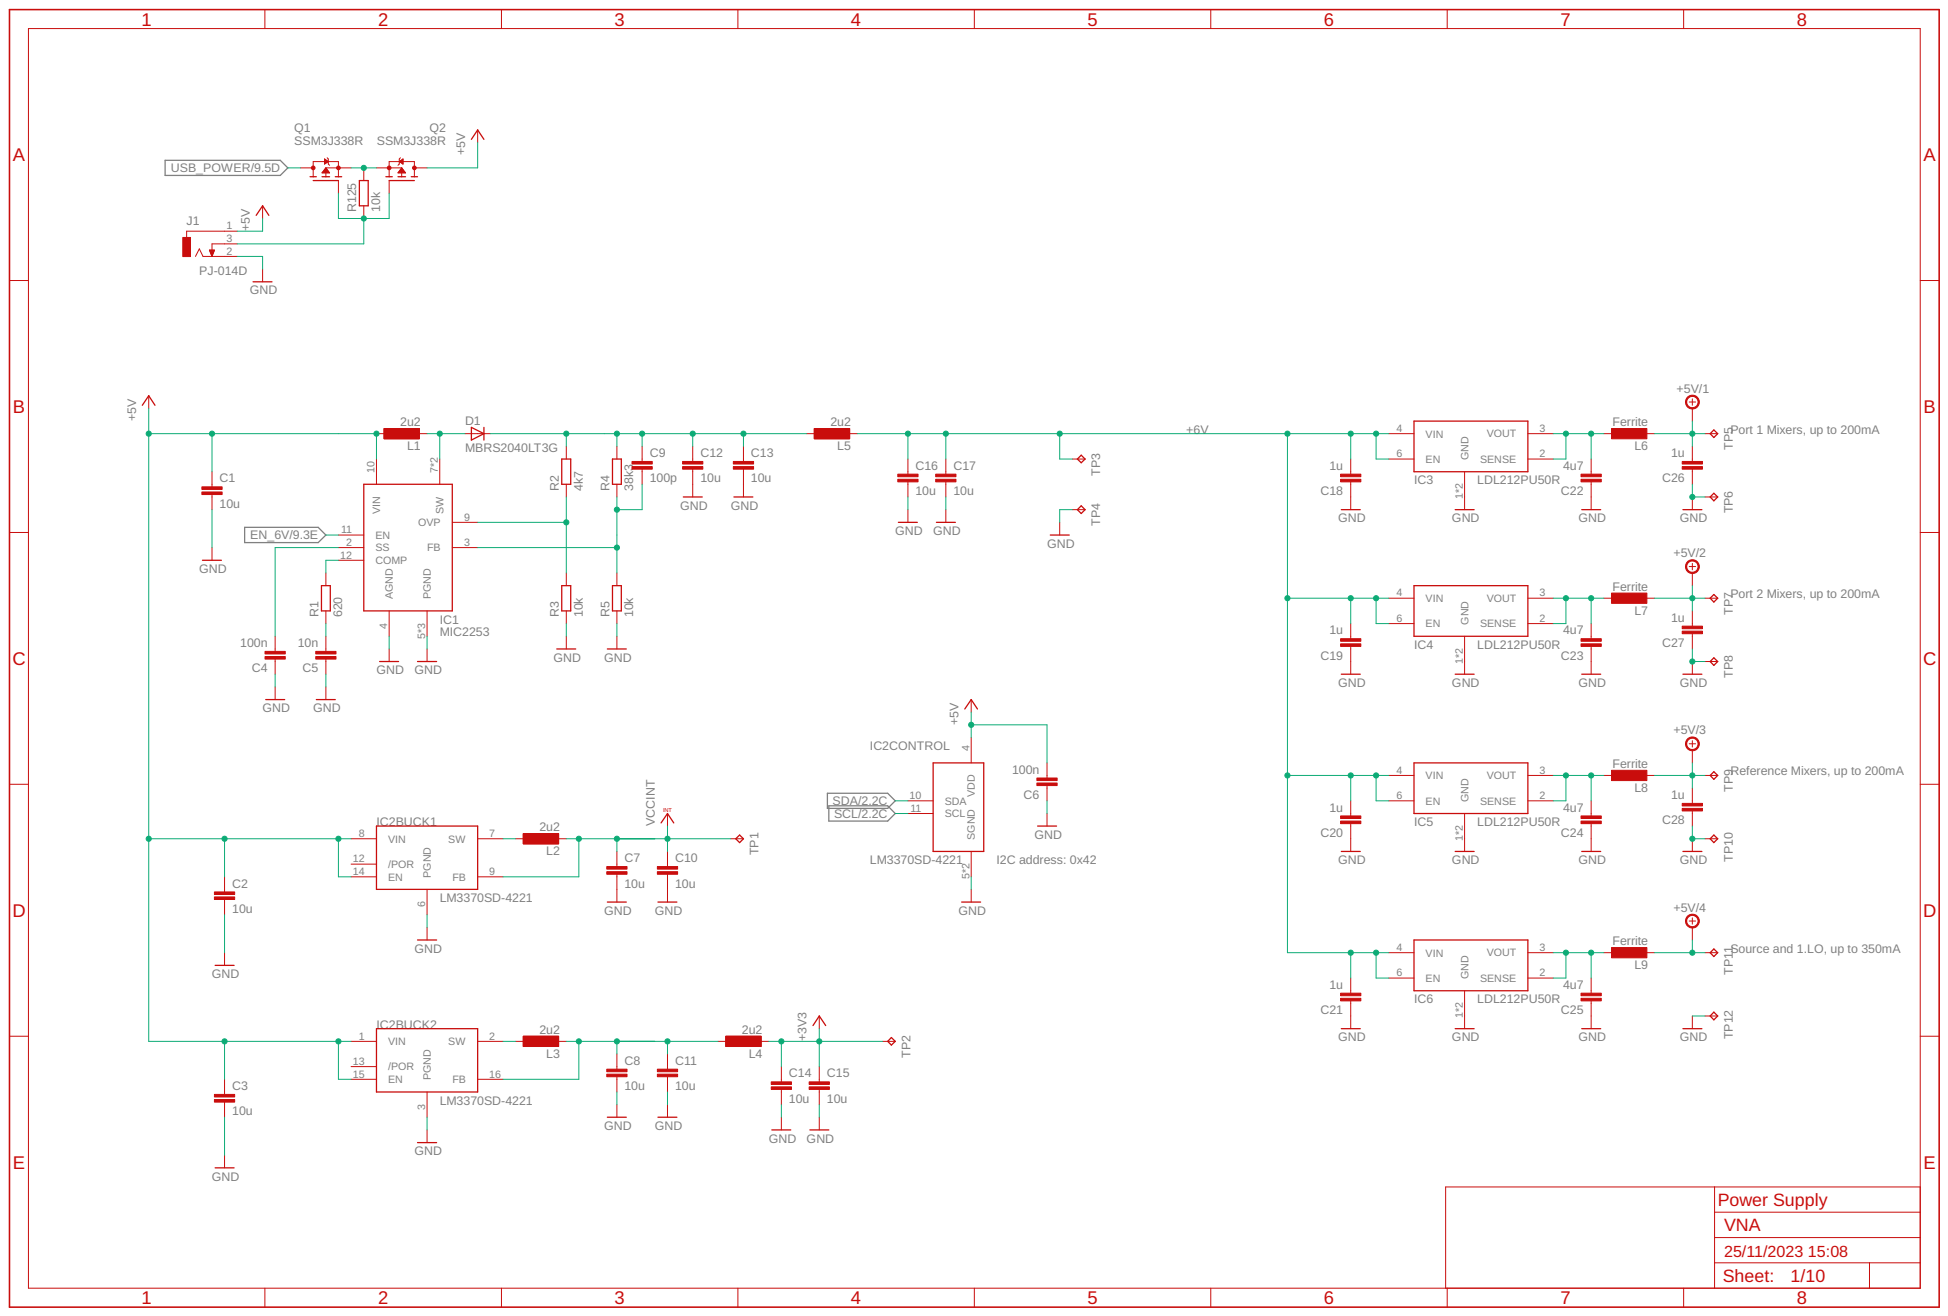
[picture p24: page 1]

Port 1 Mixers, up to 200mA

Port 2 Mixers, up to 200mA

Reference Mixers, up to 200mA

Source and 1.LO, up to 350mA

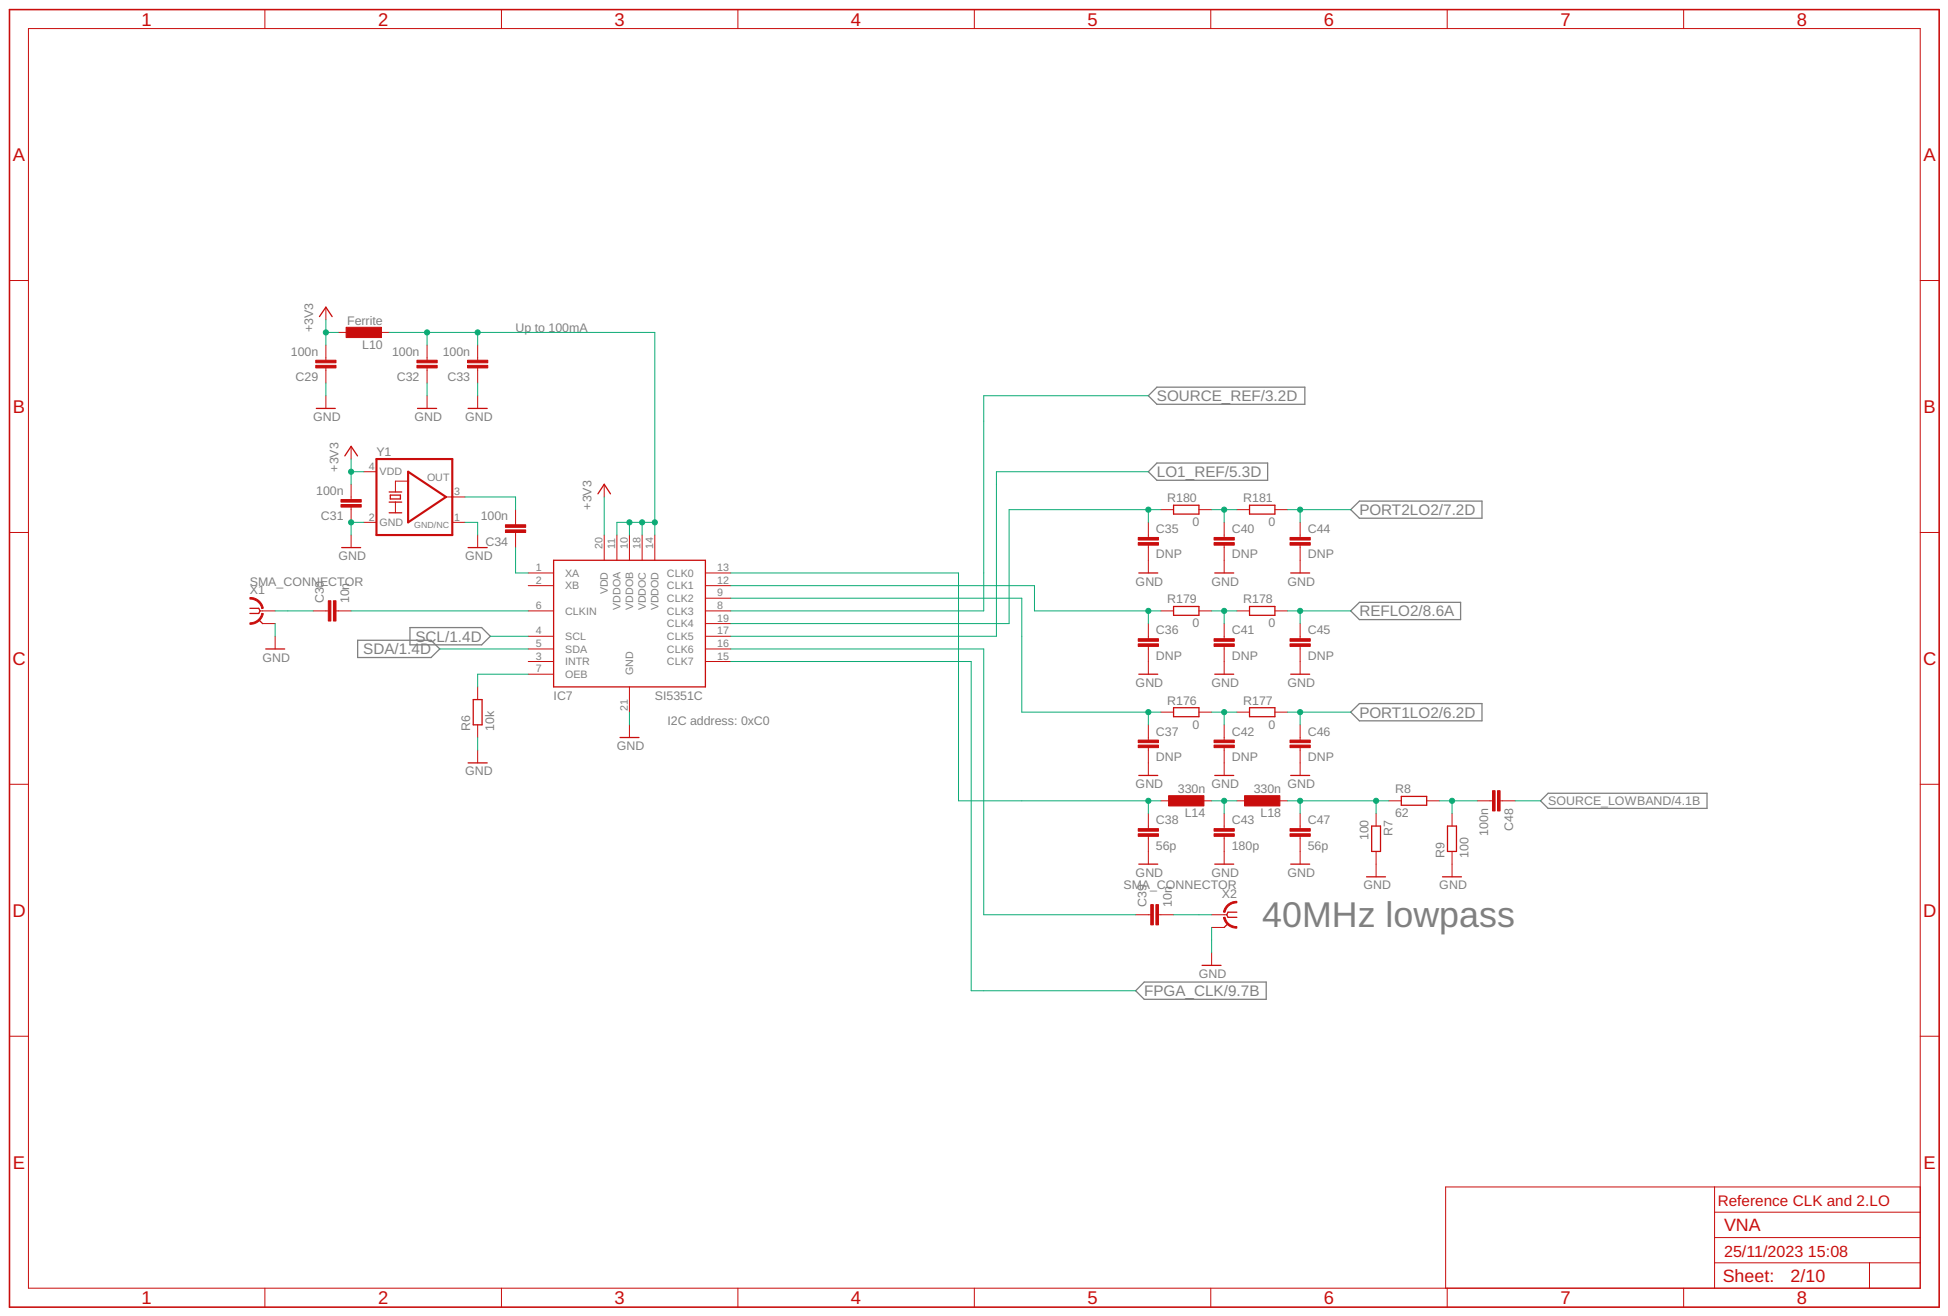
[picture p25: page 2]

Reference CLK and 2.LO
VNA

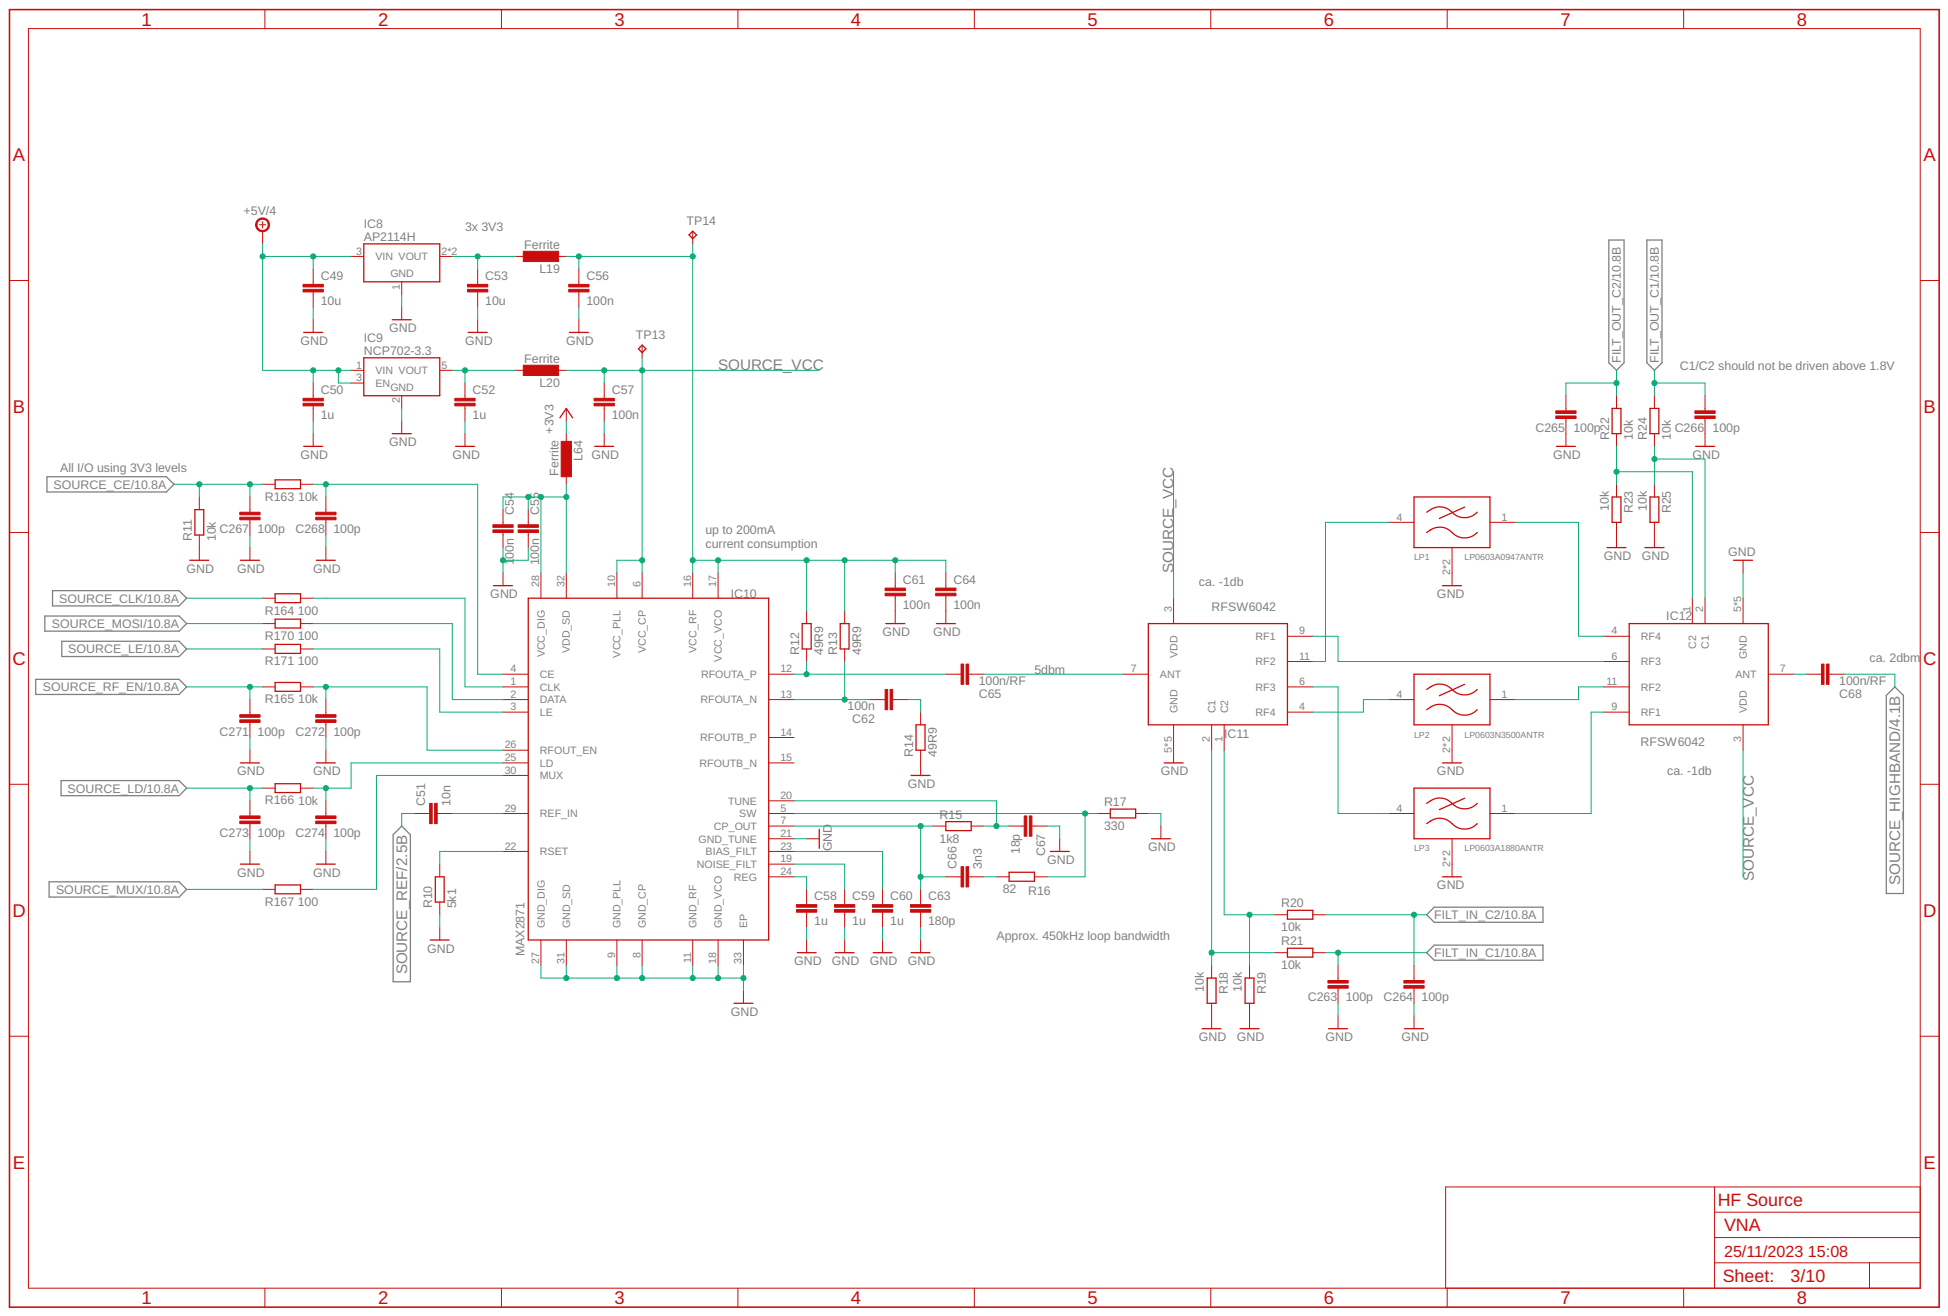
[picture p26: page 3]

C1/C2 should not be driven above 1.8V

GND
GND GND GND

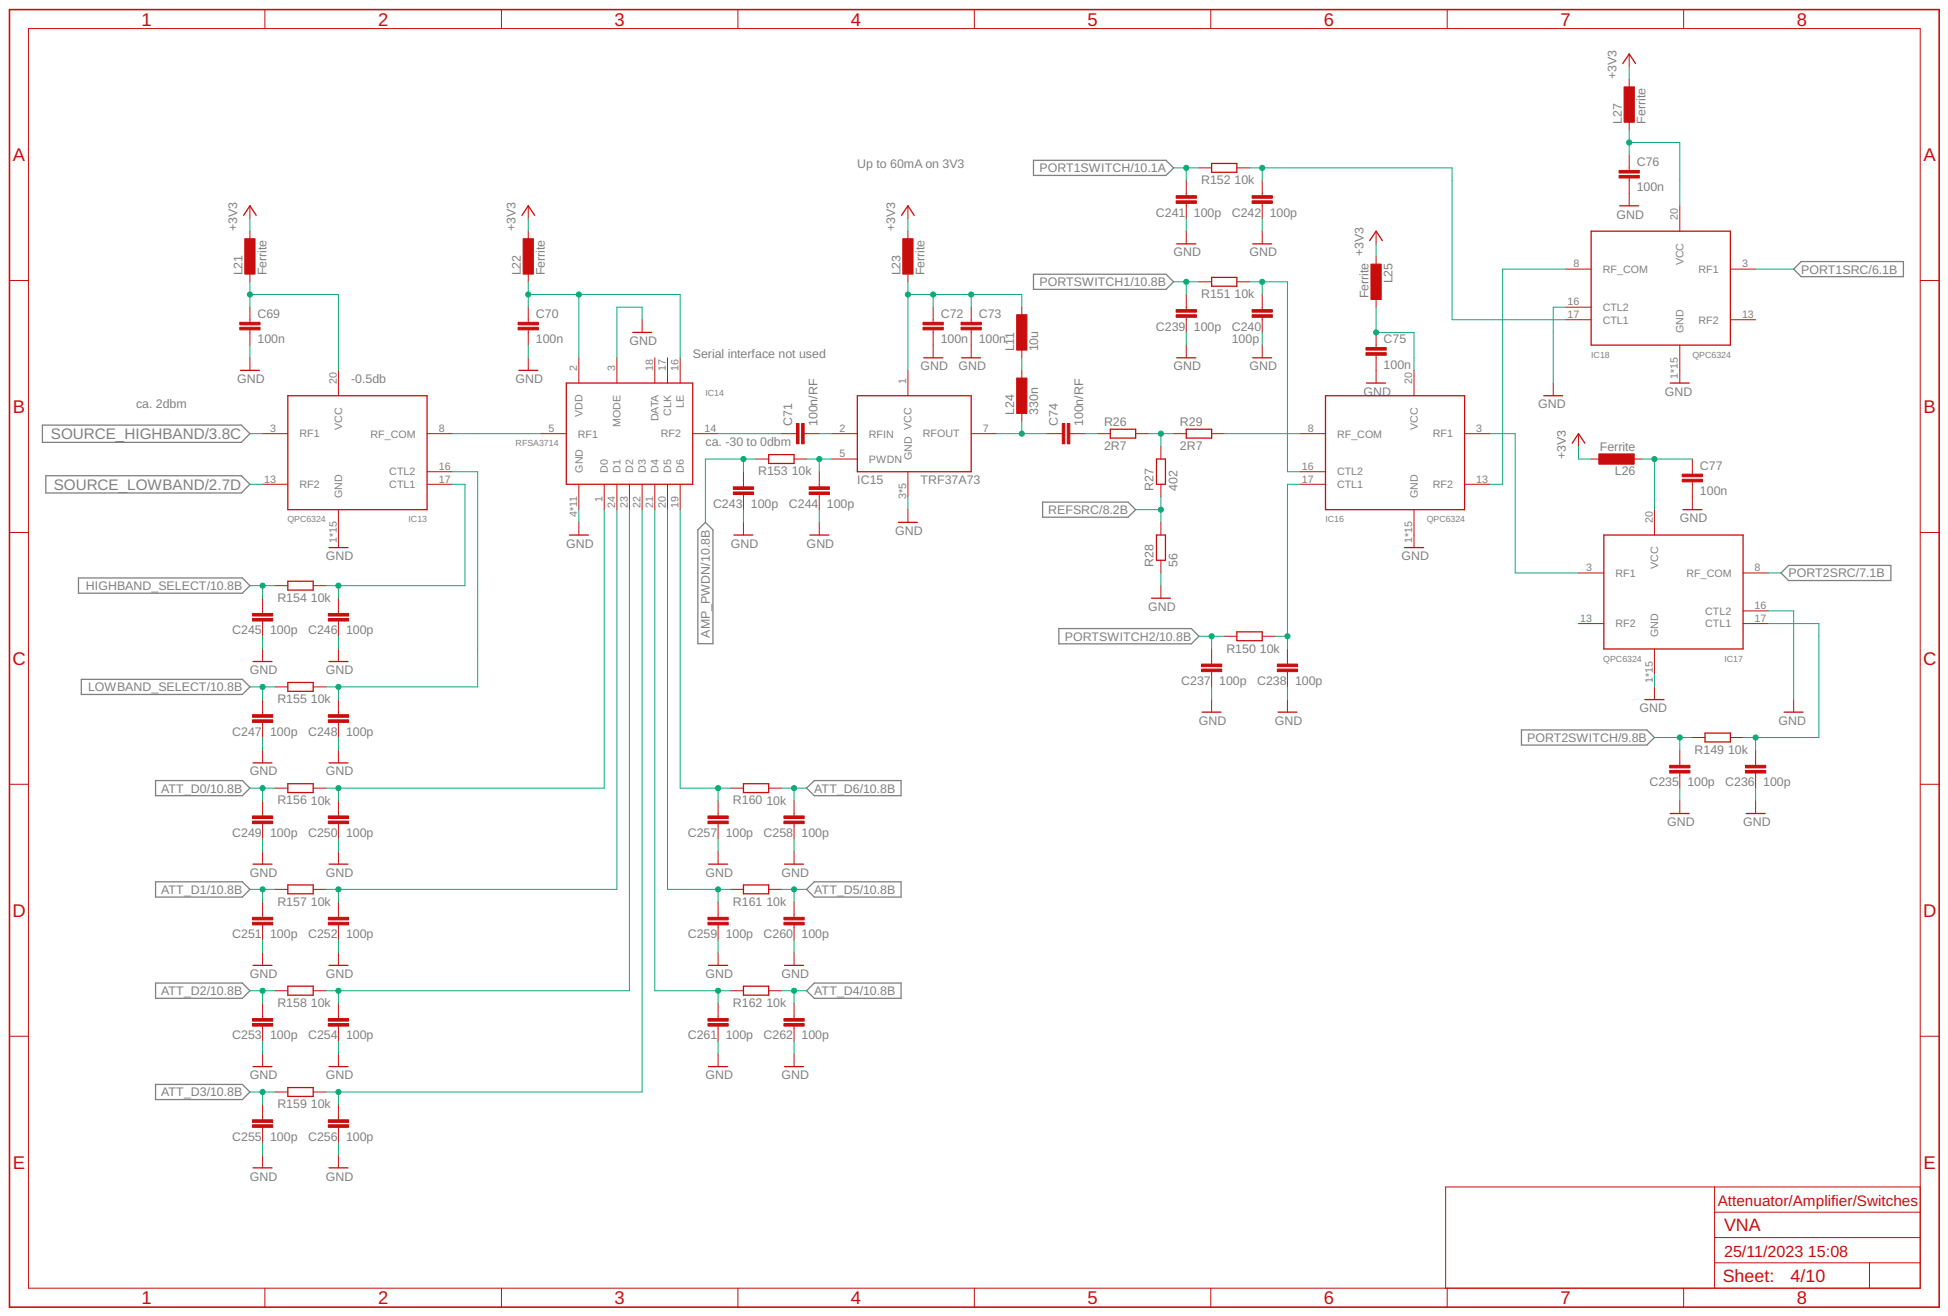
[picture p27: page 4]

Serial interface not used

Attenuator/Amplifier/Switches Sheet:
VNA

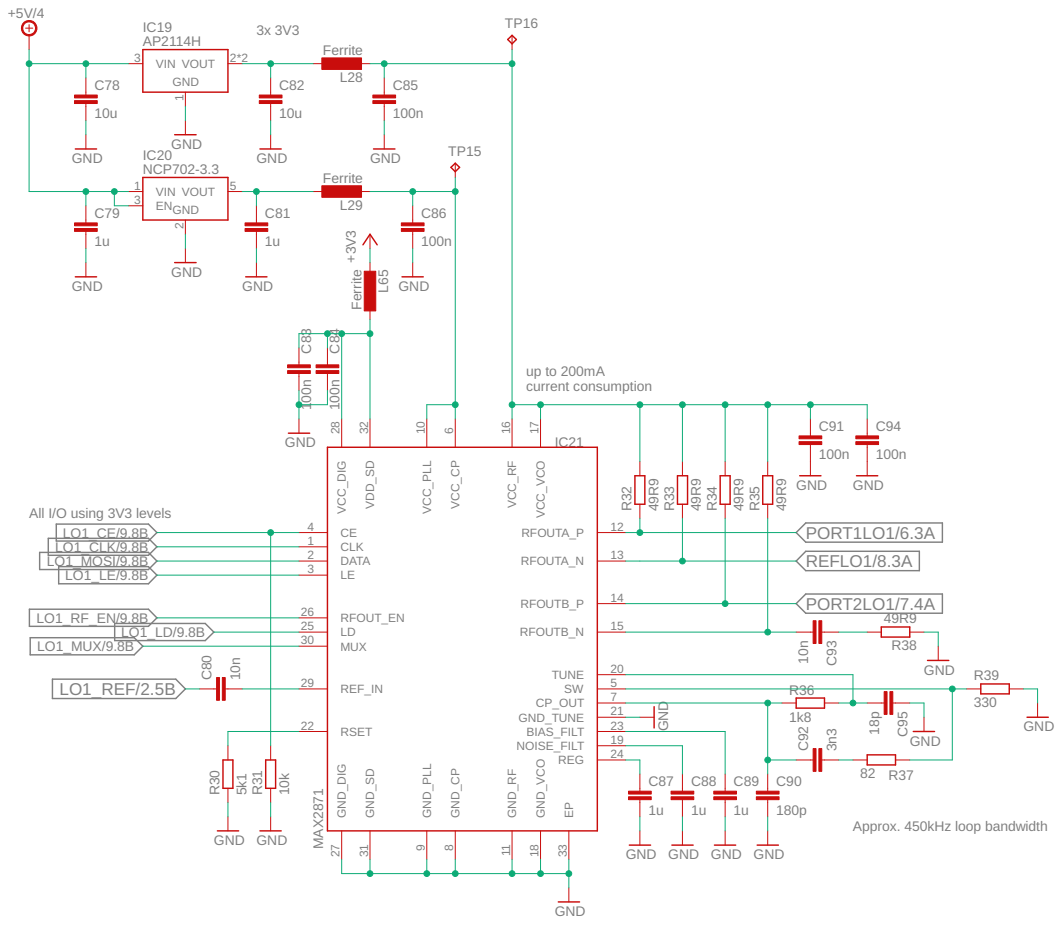
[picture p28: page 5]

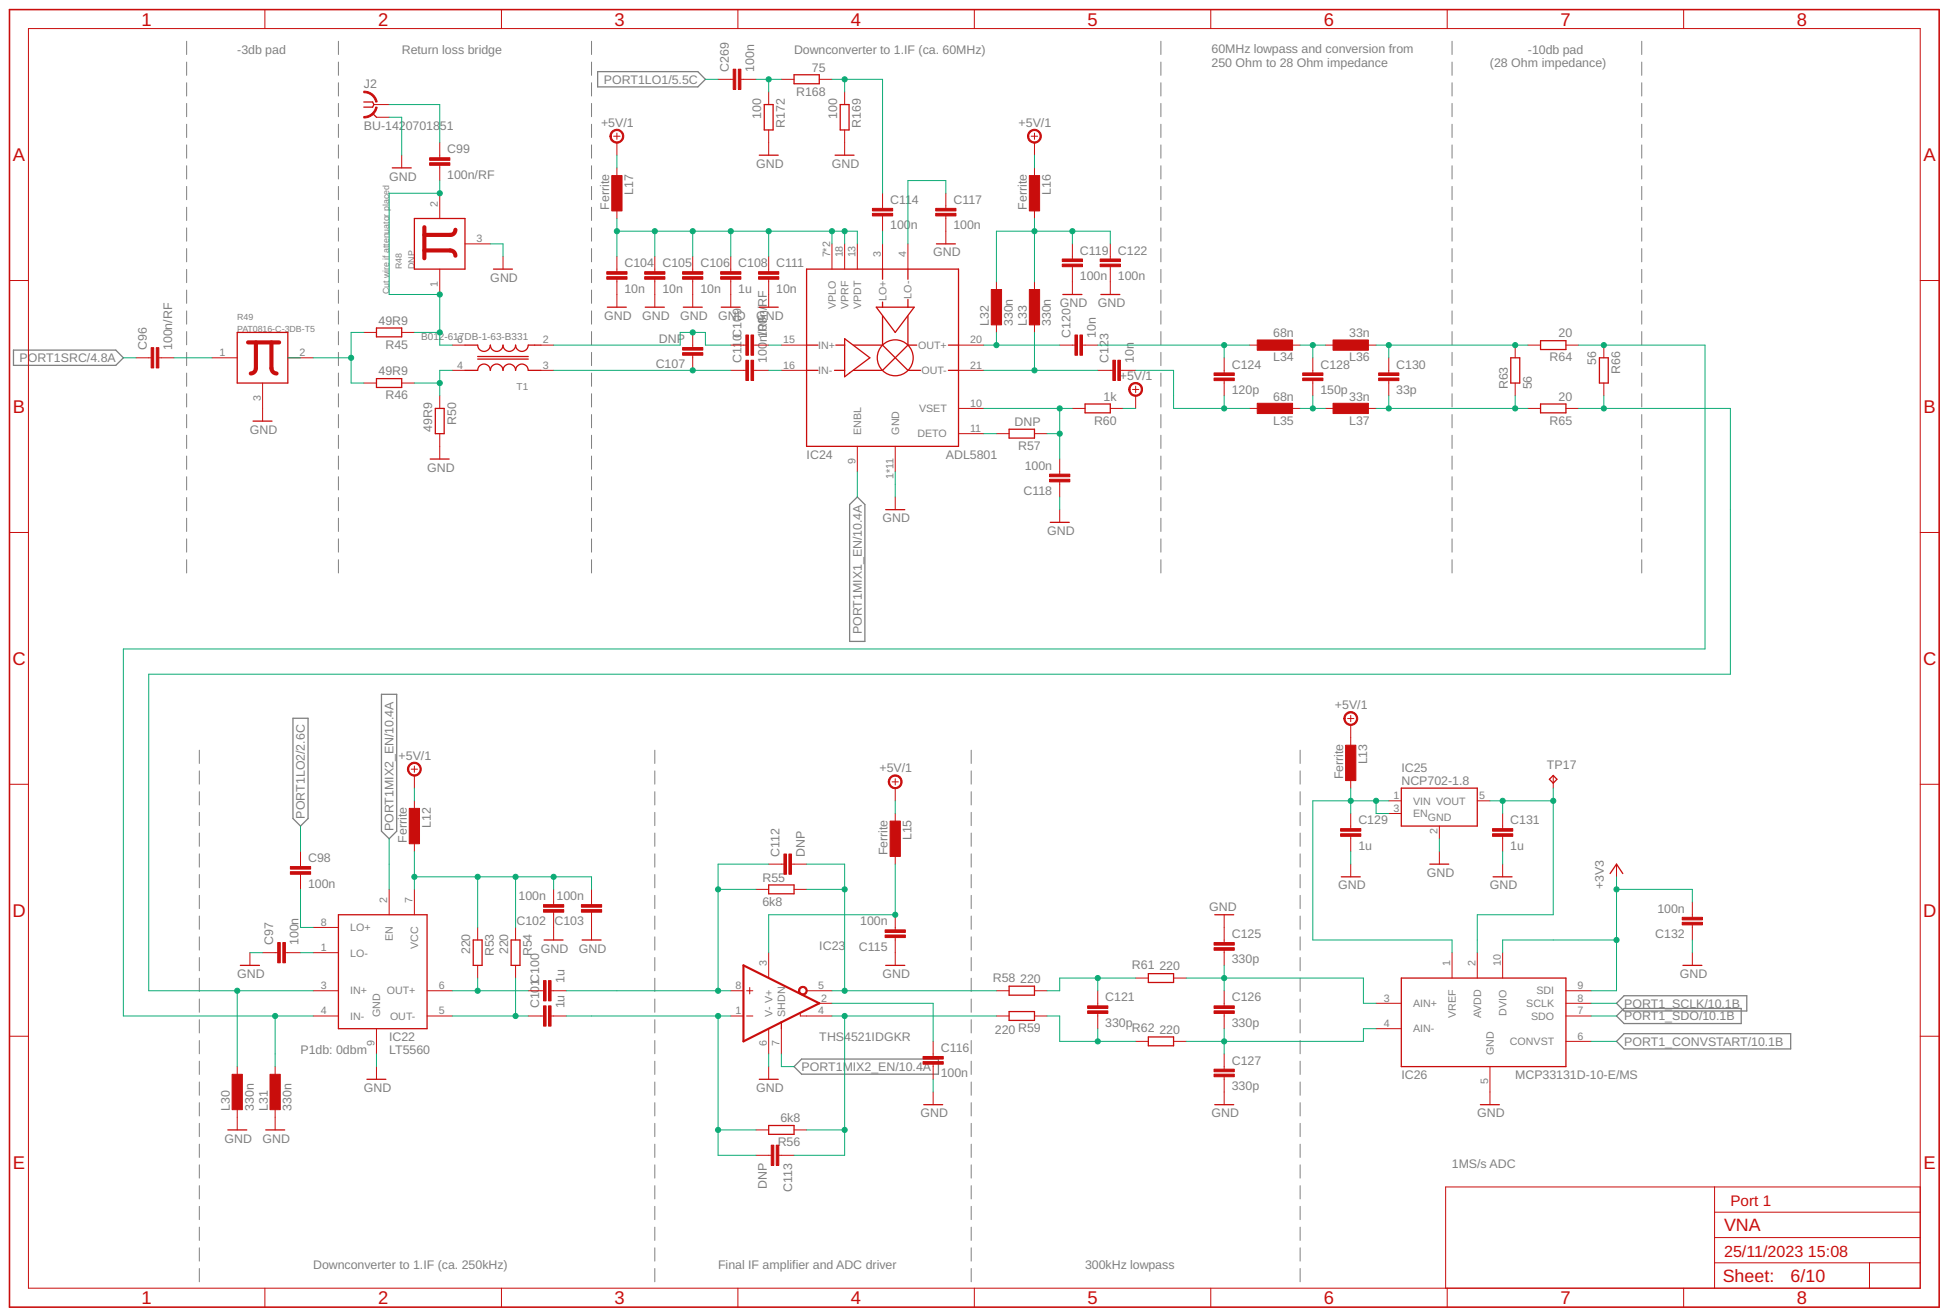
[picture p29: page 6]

250 Ohm to 28 Ohm impedance

Cut wire if attenuator placed

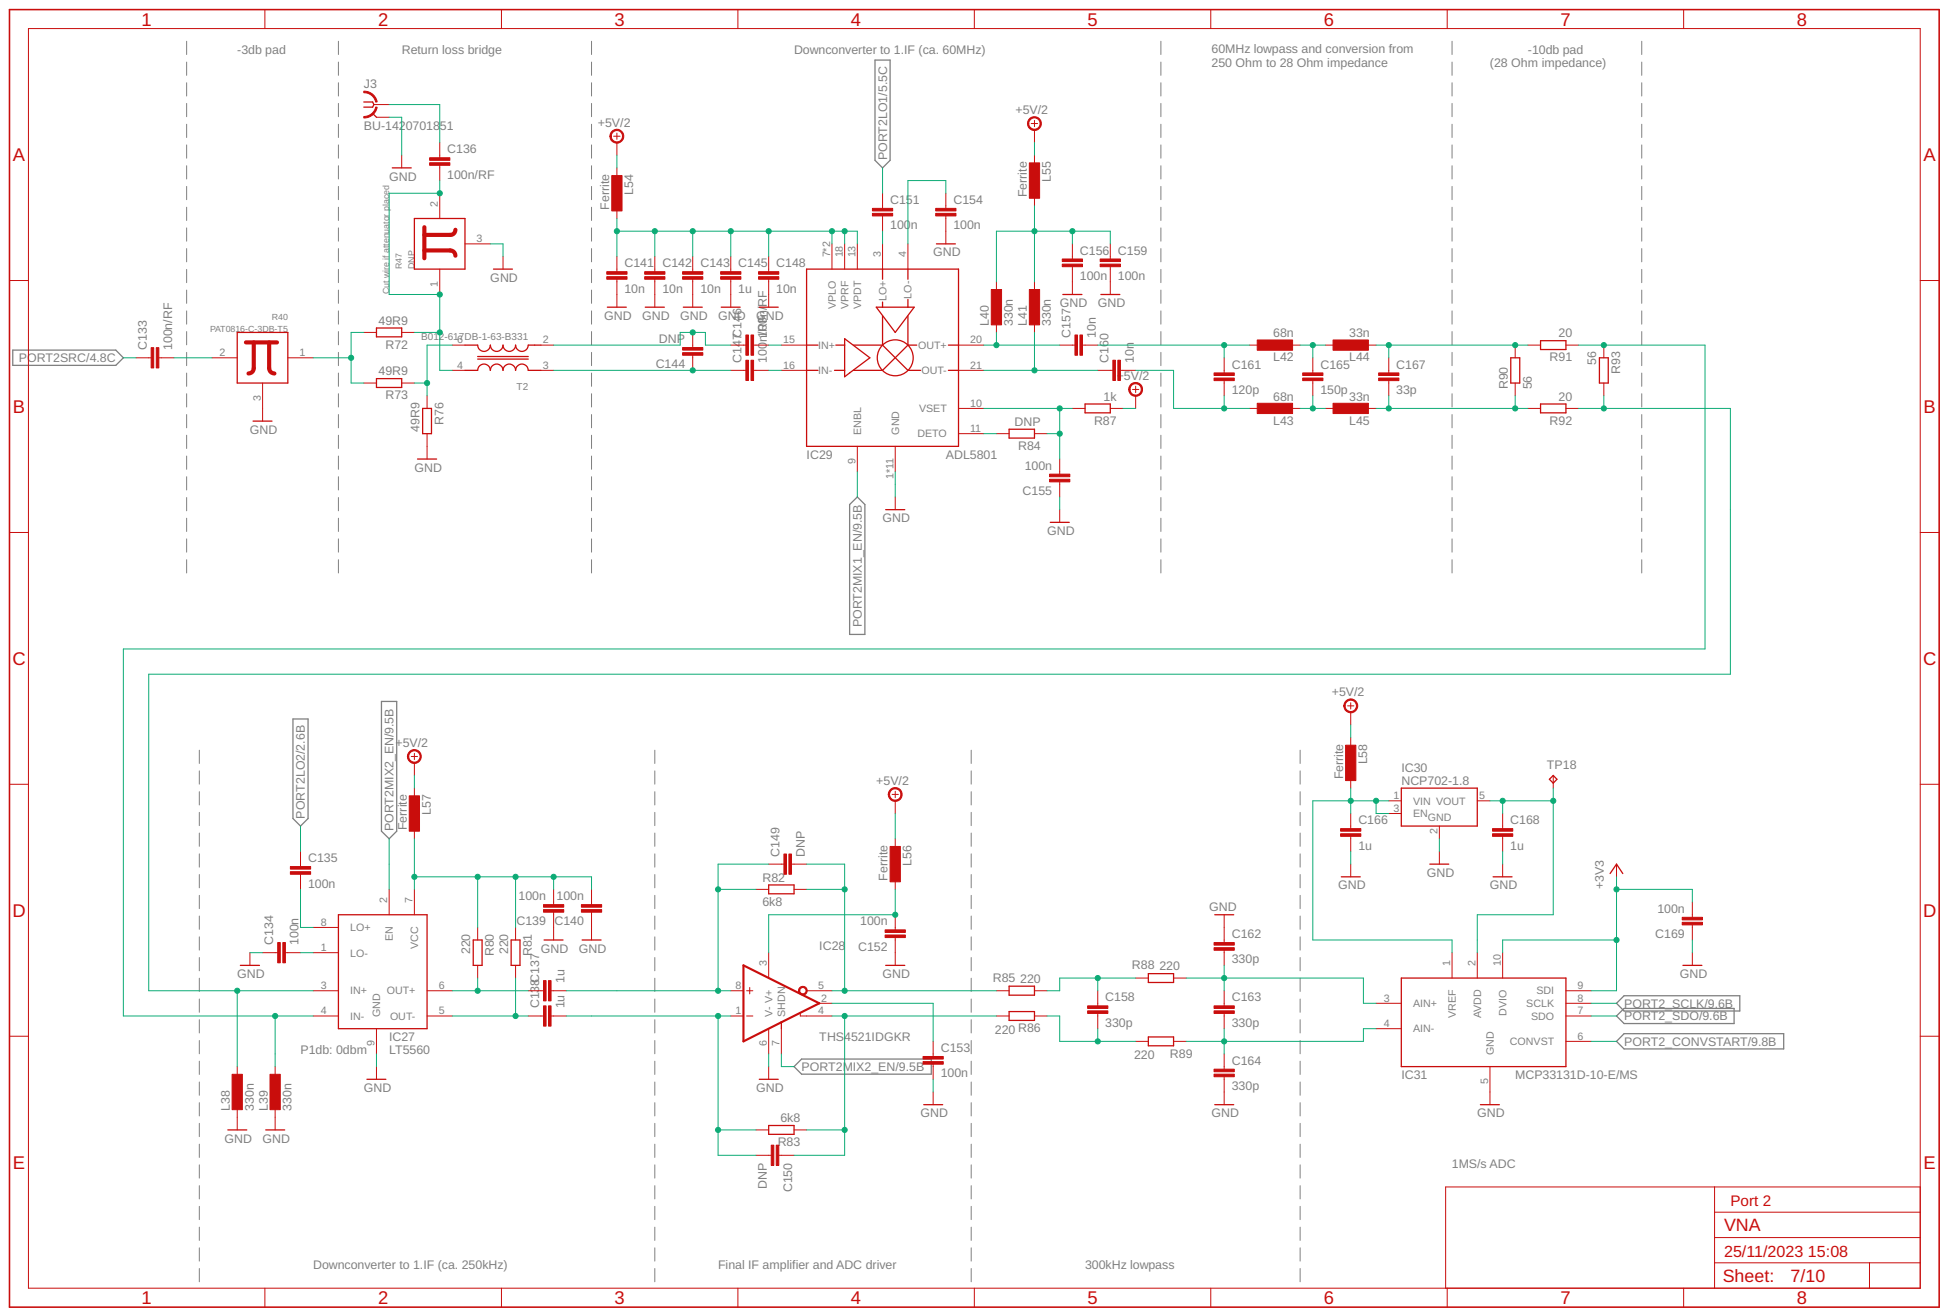
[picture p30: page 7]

250 Ohm to 28 Ohm impedance

Cut wire if attenuator placed

IN- 16 | 11 NBL

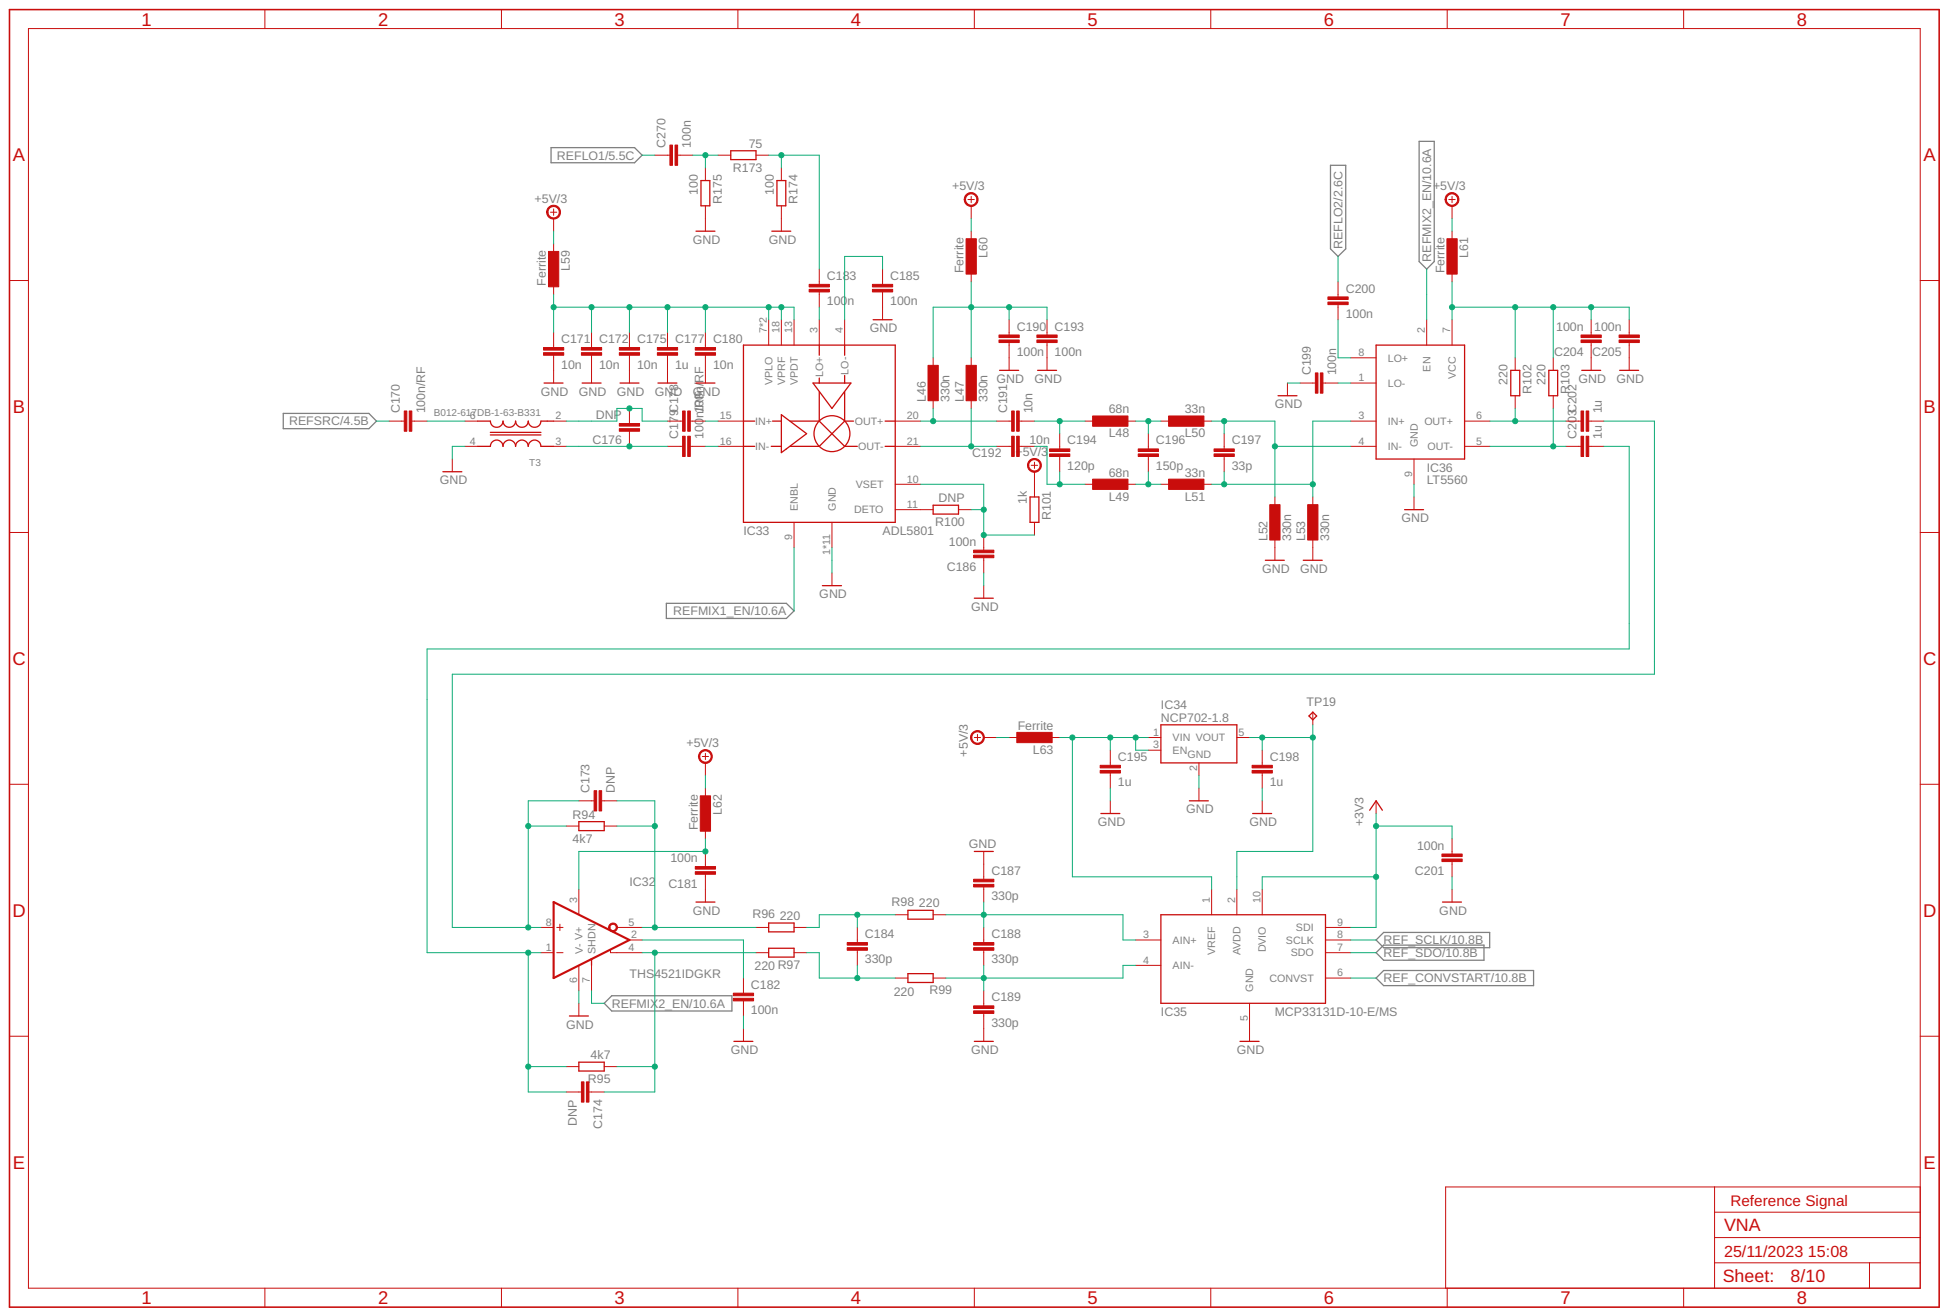
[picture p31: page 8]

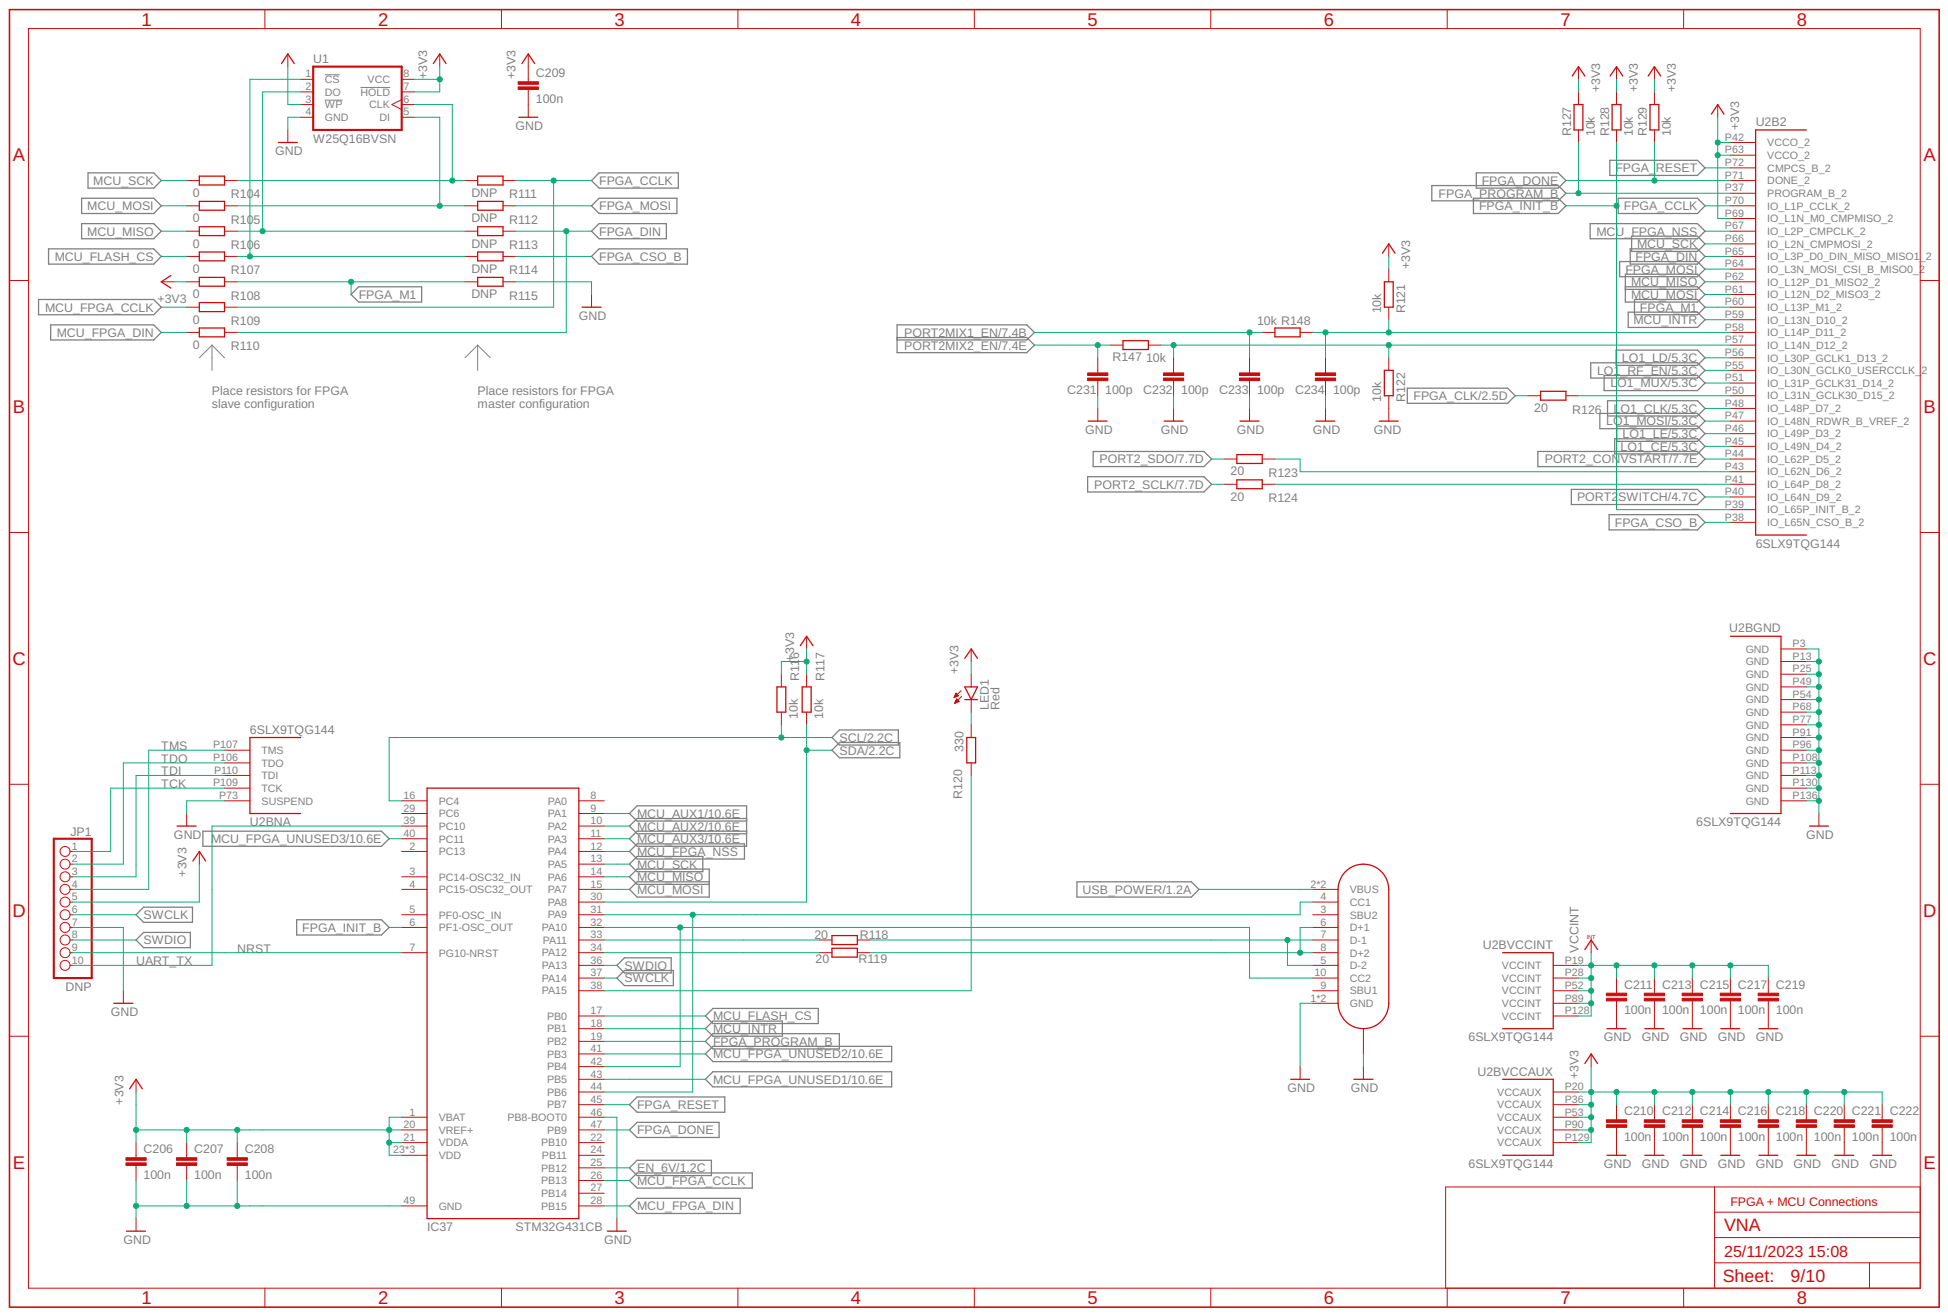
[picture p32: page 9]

DNP DNP DNP DNP DNP +3V3

Place resistors for FPGA master configuration Place resistors for FPGA
slave configuration

31 PA10
32 PA11 33 PA12 | 20 R119 R118

34 PA13 SWDIO | 20

18 PB2 | MCU_INTR
19 PB3 41 PB4 | FPGA_PROGRAM_B

GND GND

GND GND GND GND GND

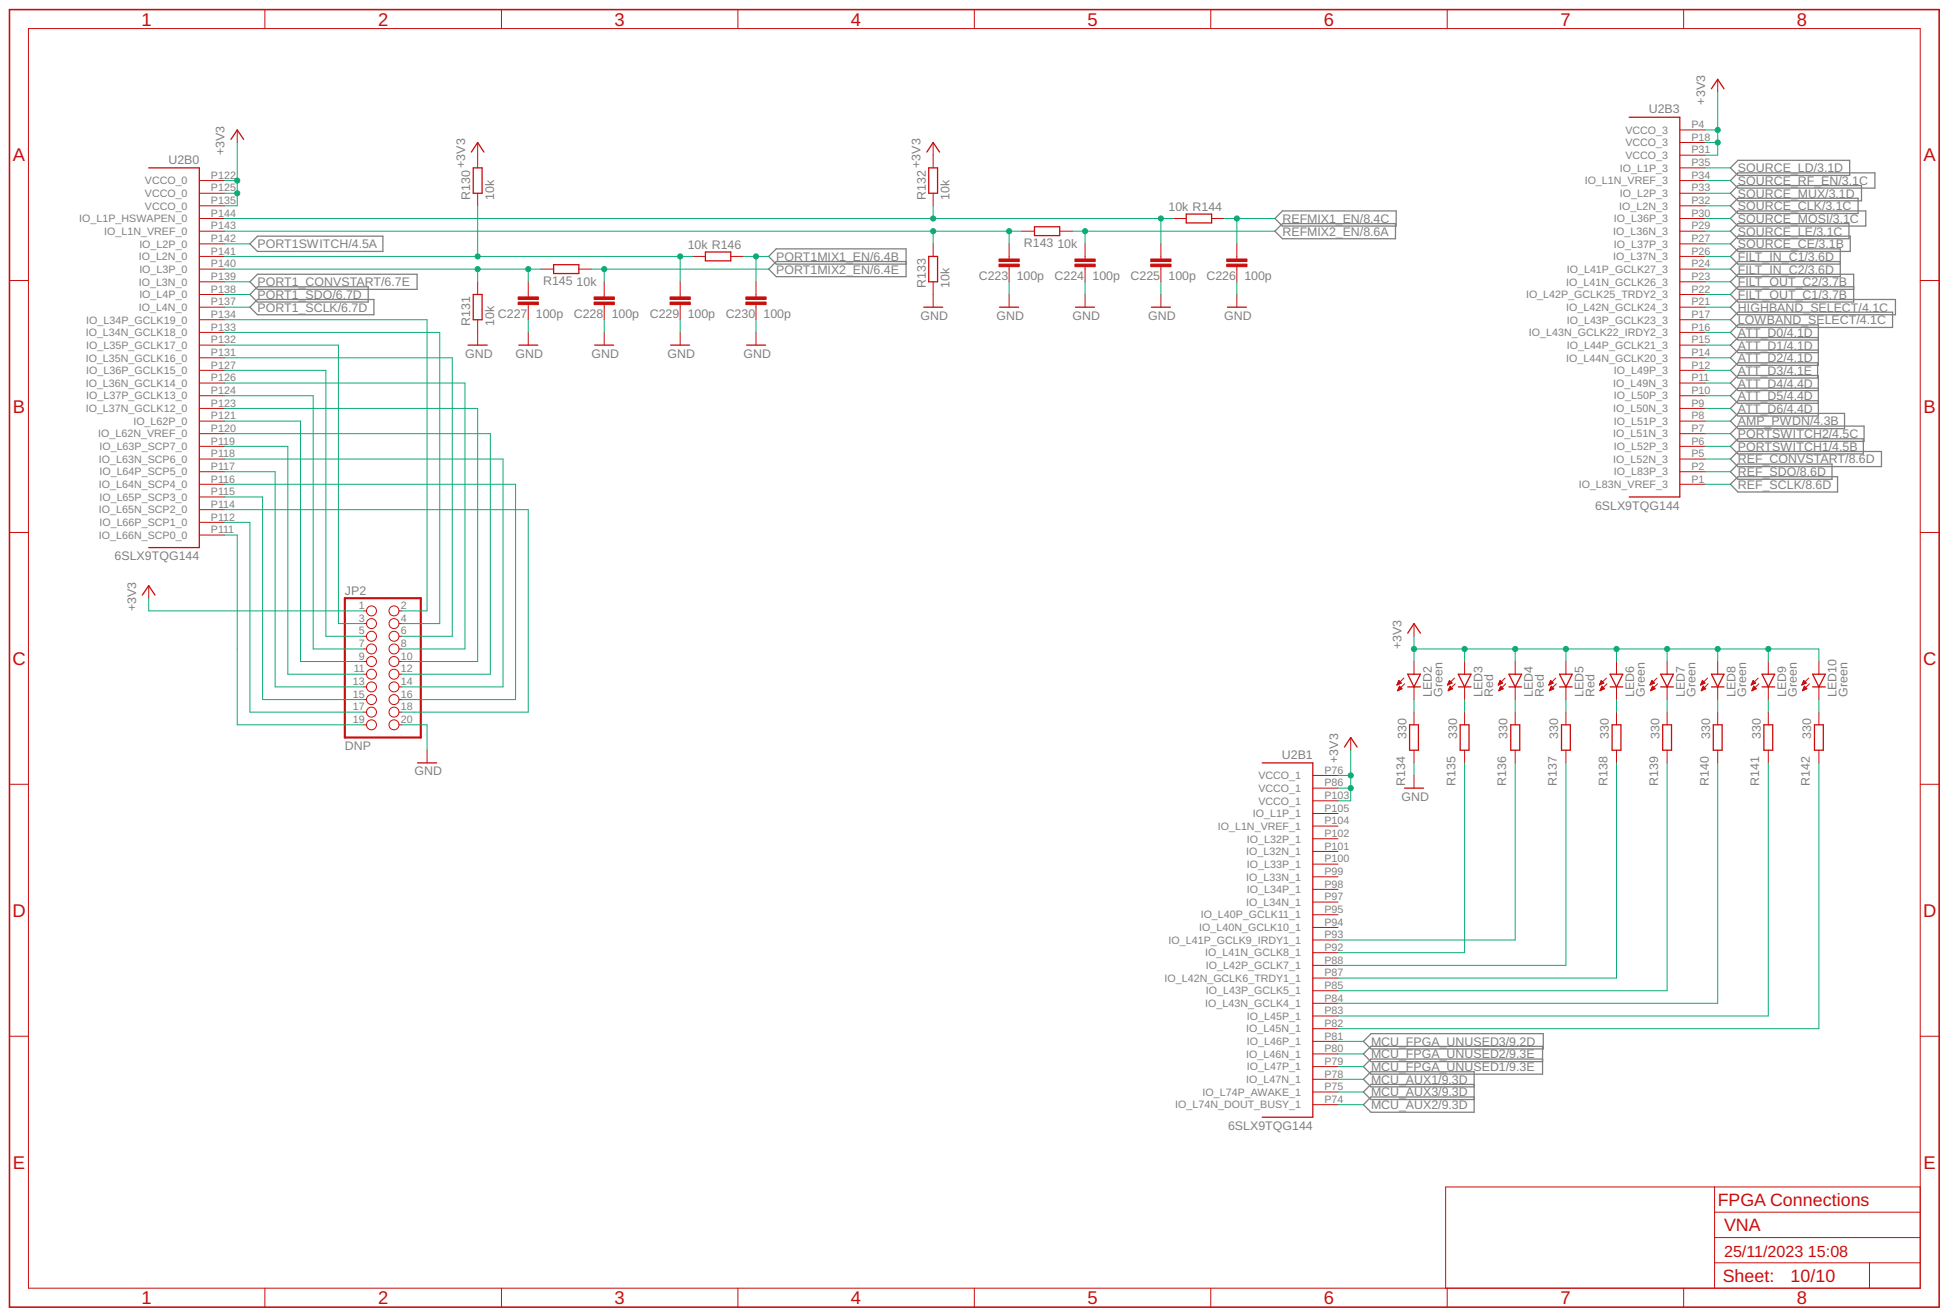
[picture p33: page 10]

Green Red Red Red Green Green Green Green Green

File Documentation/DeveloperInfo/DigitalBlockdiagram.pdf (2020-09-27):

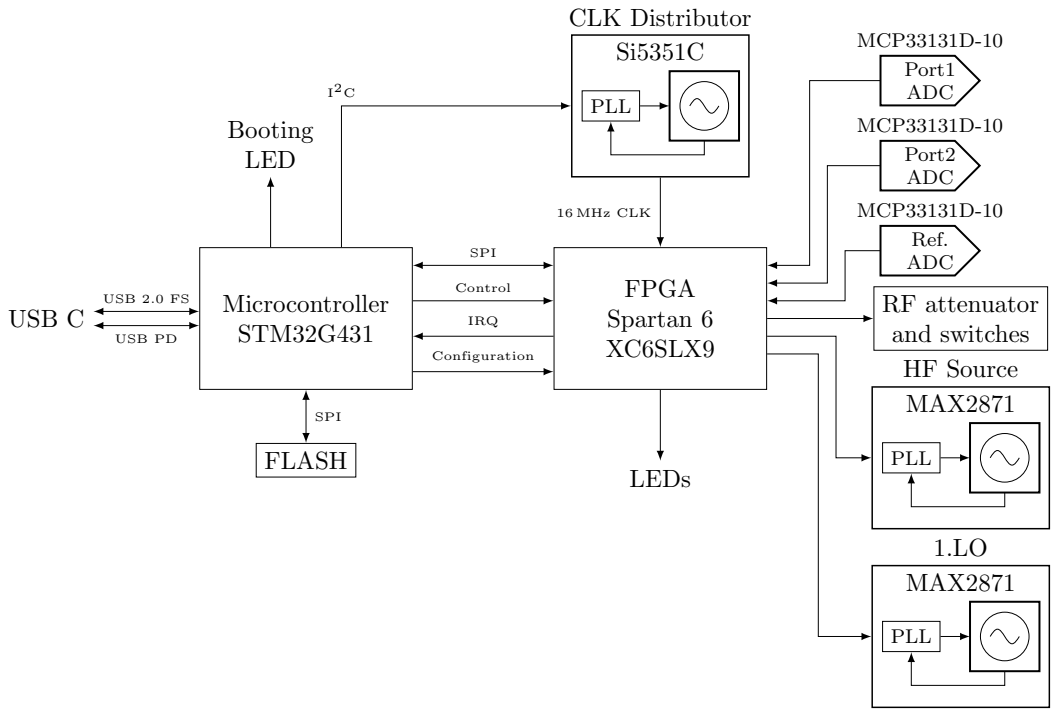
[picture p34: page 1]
STM32G431 USB C; USB 2.0 FS; USB PD; Booting LED; FLASH; SPI; Control; IRQ; Configuration; LEDs; PLL; CLK Distributor; 16 MHz CLK; Port1 ADC; MCP33131D-10; Port2 ADC; Ref. ADC; RF attenuator and switches; HF Source; MAX2871

Microcontroller | FPGA Spartan 6 XC6SLX9

MAX2871

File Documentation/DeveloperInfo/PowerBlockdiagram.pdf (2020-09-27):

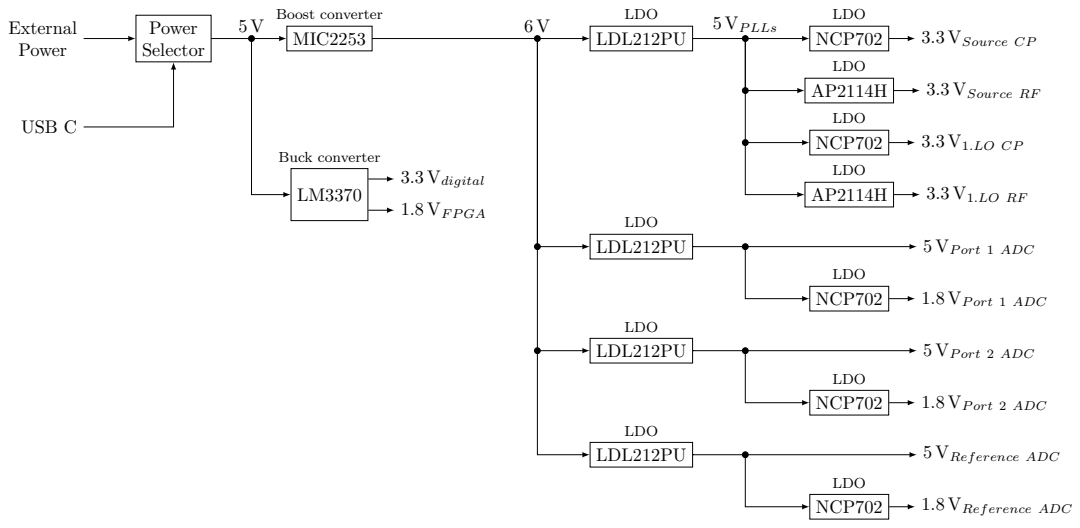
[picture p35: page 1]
Power Selector; USB C; External Power; MIC2253; Boost converter; Buck converter; 3.3 Vdigital; LDL212PU; LDO; 5 VP LLs; NCP702; 3.3 VSource CP; 3.3 VSource RF

5 VP ort 1 ADC

1.8 VP ort 1 ADC

5 VP ort 2 ADC

1.8 VP ort 2 ADC

5 VRef erence ADC

1.8 VRef erence ADC

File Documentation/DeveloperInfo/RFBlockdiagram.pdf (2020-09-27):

# 3x QPC6324⁵⁰ Ω

### Port 1

PLL; LF Source CLK Distributor 2.LO; 10 MHz in 10 MHz out; 26 MHz; MAX2871; HF Source; 100 MHz; RFSW6024; 900 MHz; 1800 MHz; 3500 MHz; QPC6324; 40 MHz; RFSA3714; TRF37A73; ADL5801 70 MHz LT5560 300 kHz; THS4521; ADC; MCP33131D-10; Port 2; 300 kHz; 70 MHz; ADL5801

1 MHz to 25 MHz


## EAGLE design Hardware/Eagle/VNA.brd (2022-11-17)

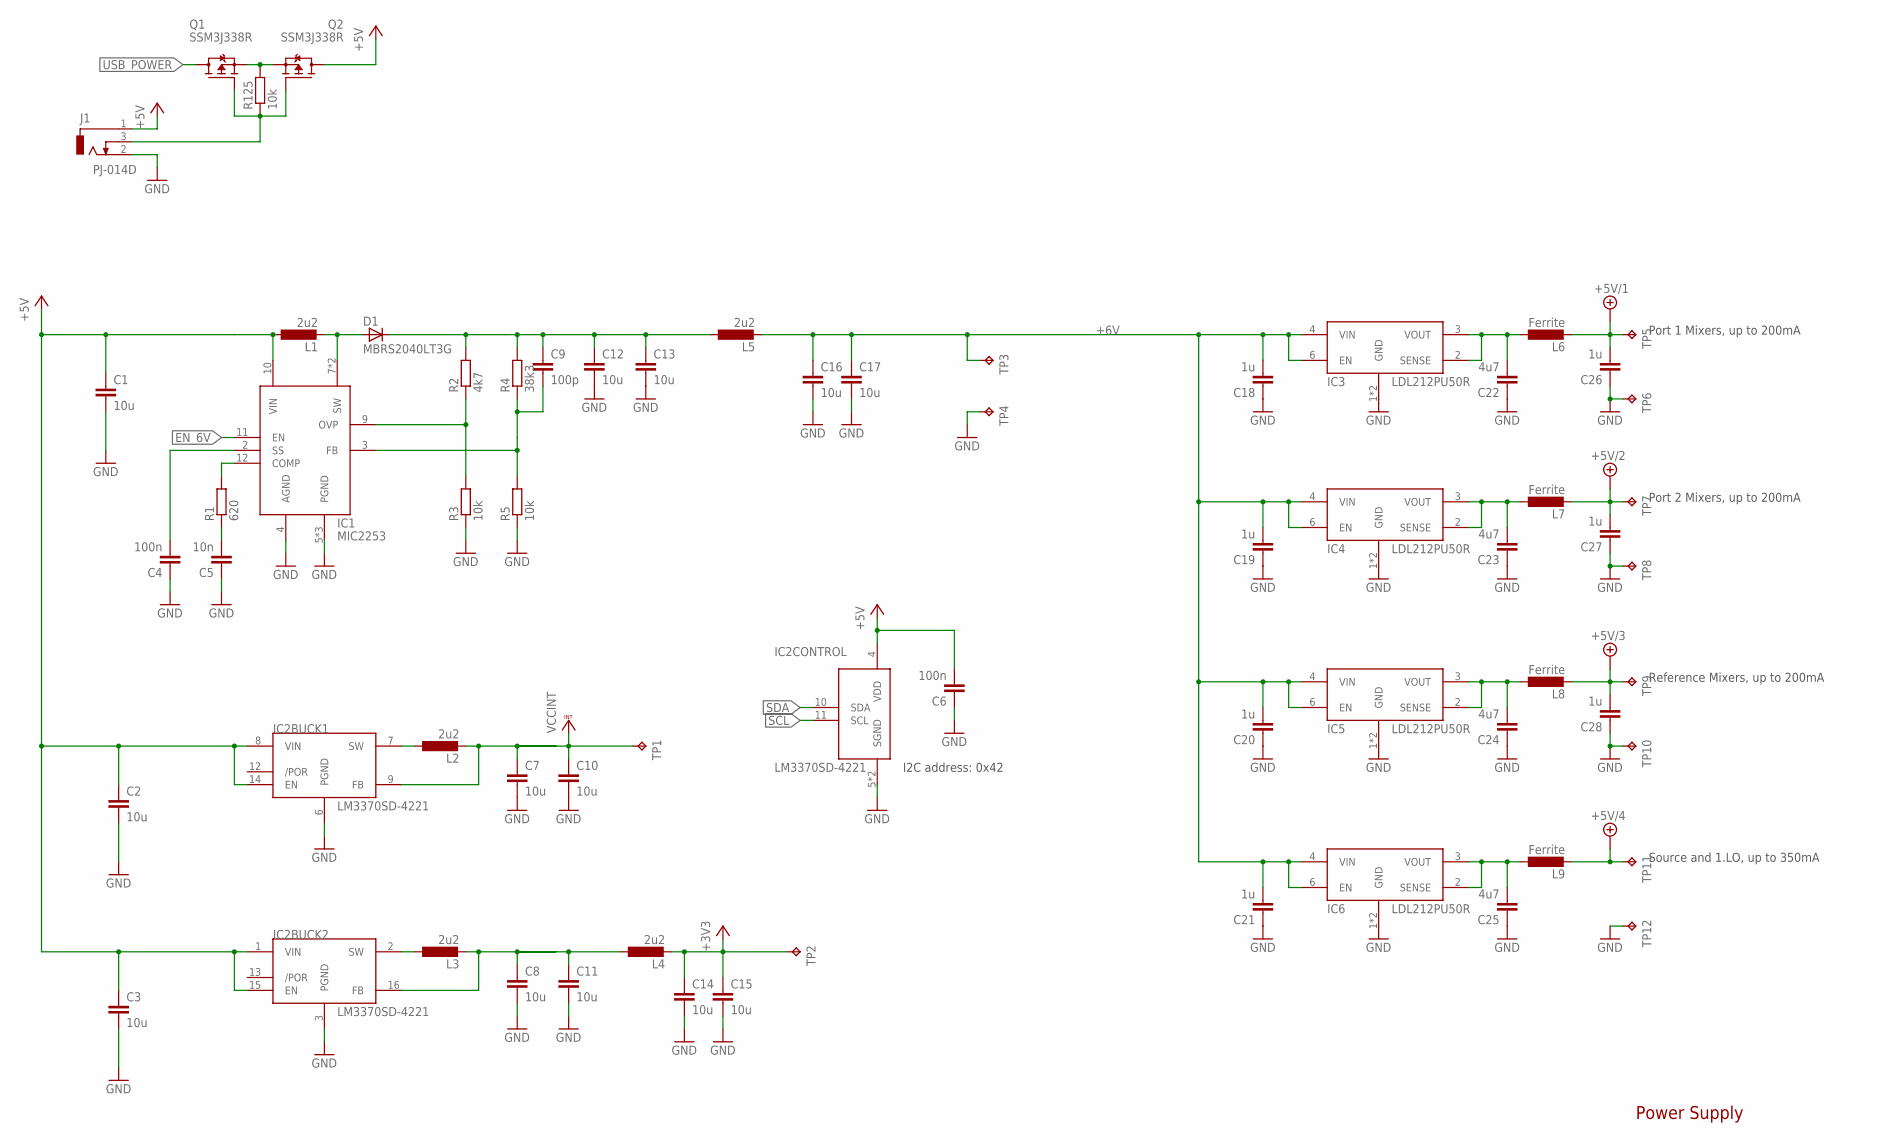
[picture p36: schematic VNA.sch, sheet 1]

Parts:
C1, C2, C3, C7, C8, C10, C11, C12, C13, C14, C15, C16, C17: 10u; C1206
C4, C6: 100n; C0402
C5: 10n; C0402
C9: 100p; C0402
C18, C19, C20, C21, C26, C27, C28: 1u; C0603
C22, C23, C24, C25: 4u7; C0603
D1: MBRS2040LT3G; SMB
IC1: MIC2253; SON50P300X300X90-13T170X240N
IC2: LM3370SD-4221; SON50P400X500X80-17T260X400N
IC3, IC4, IC5, IC6: LDL212PU50R; SON95P300X300X100-7T170X240N
J1: PJ-014D
L1, L2, L3, L4, L5: 2u2; SRN5040
L6, L7, L8, L9: Ferrite; R0402
Q1, Q2: SSM3J338R; SOTFL95P240X80-3N
R1: 620; R0402
R2: 4k7; R0402
R3, R5, R125: 10k; R0402
R4: 38k3; R0402
TP1, TP2, TP3, TP4, TP5, TP6, TP7, TP8, TP9, TP10, TP11, TP12: TPB1,27; B1,27

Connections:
+3V3: C14.1, C15.1, L4.P$2 (2), TP2.TP; also elsewhere on the board
+5V: C1.1, C2.1, C3.1, C6.2, IC1.10 (VIN), IC2.1 (VIN), IC2.4 (VDD), IC2.8 (VIN), IC2.14 (EN), IC2.15 (EN), J1.1, L1.P$1 (1), Q2.3 (D)
+5V/1: C26.2, L6.2, TP5.TP; also elsewhere on the board
+5V/2: C27.2, L7.2, TP7.TP; also elsewhere on the board
+5V/3: C28.2, L8.2, TP9.TP; also elsewhere on the board
+5V/4: L9.2, TP11.TP; also elsewhere on the board
+6V: C16.1, C17.1, C18.2, C19.2, C20.2, C21.2, IC3.4 (VIN), IC3.6 (EN), IC4.4 (VIN), IC4.6 (EN), IC5.4 (VIN), IC5.6 (EN), IC6.4 (VIN), IC6.6 (EN), L5.P$2 (2), TP3.TP
EN_6V: IC1.11 (EN); also elsewhere on the board
GND: C1.2, C2.2, C3.2, C4.1, C5.1, C6.1, C7.2, C8.2, C10.2, C11.2, C12.2, C13.2, C14.2, C15.2, C16.2, C17.2, C18.1, C19.1, C20.1, C21.1, C22.1, C23.1, C24.1, C25.1, C26.1, C27.1, C28.1, IC1.4 (AGND), IC1.5 (PGND), IC1.6 (PGND), IC1.13 (PGND), IC2.3 (PGND), IC2.5 (SGND), IC2.6 (PGND), IC2.17 (SGND), IC3.1 (GND), IC3.7 (GND), IC4.1 (GND), IC4.7 (GND), IC5.1 (GND), IC5.7 (GND), IC6.1 (GND), IC6.7 (GND), J1.2, R3.1, R5.1, TP4.TP, TP6.TP, TP8.TP, TP10.TP, TP12.TP; also elsewhere on the board
unnamed: D1.A, IC1.7 (SW), IC1.8 (SW), L1.P$2 (2)
unnamed: IC1.12 (COMP), R1.2
unnamed: C22.2, IC3.2 (SENSE), IC3.3 (VOUT), L6.1
unnamed: C9.2, IC1.3 (FB), R4.1, R5.2
unnamed: C23.2, IC4.2 (SENSE), IC4.3 (VOUT), L7.1
unnamed: IC1.9 (OVP), R2.1, R3.2
unnamed: C24.2, IC5.2 (SENSE), IC5.3 (VOUT), L8.1
unnamed: C4.2, IC1.2 (SS)
unnamed: C25.2, IC6.2 (SENSE), IC6.3 (VOUT), L9.1
unnamed: Q1.2 (S), Q2.2 (S), R125.2
unnamed: J1.3, Q1.1 (G), Q2.1 (G), R125.1
unnamed: IC2.7 (SW), L2.P$1 (1)
unnamed: C9.1, C12.1, C13.1, D1.C, L5.P$1 (1), R2.2, R4.2
unnamed: IC2.2 (SW), L3.P$1 (1)
unnamed: C8.1, C11.1, IC2.16 (FB), L3.P$2 (2), L4.P$1 (1)
unnamed: C5.2, R1.1
SCL: IC2.11 (SCL); also elsewhere on the board
SDA: IC2.10 (SDA); also elsewhere on the board
USB_POWER: Q1.3 (D); also elsewhere on the board
VCCINT: C7.1, C10.1, IC2.9 (FB), L2.P$2 (2), TP1.TP; also elsewhere on the board

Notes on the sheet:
Port 1 Mixers, up to 200mA
Port 2 Mixers, up to 200mA
Reference Mixers, up to 200mA
Source and 1.LO, up to 350mA
I2C address: 0x42
Power Supply

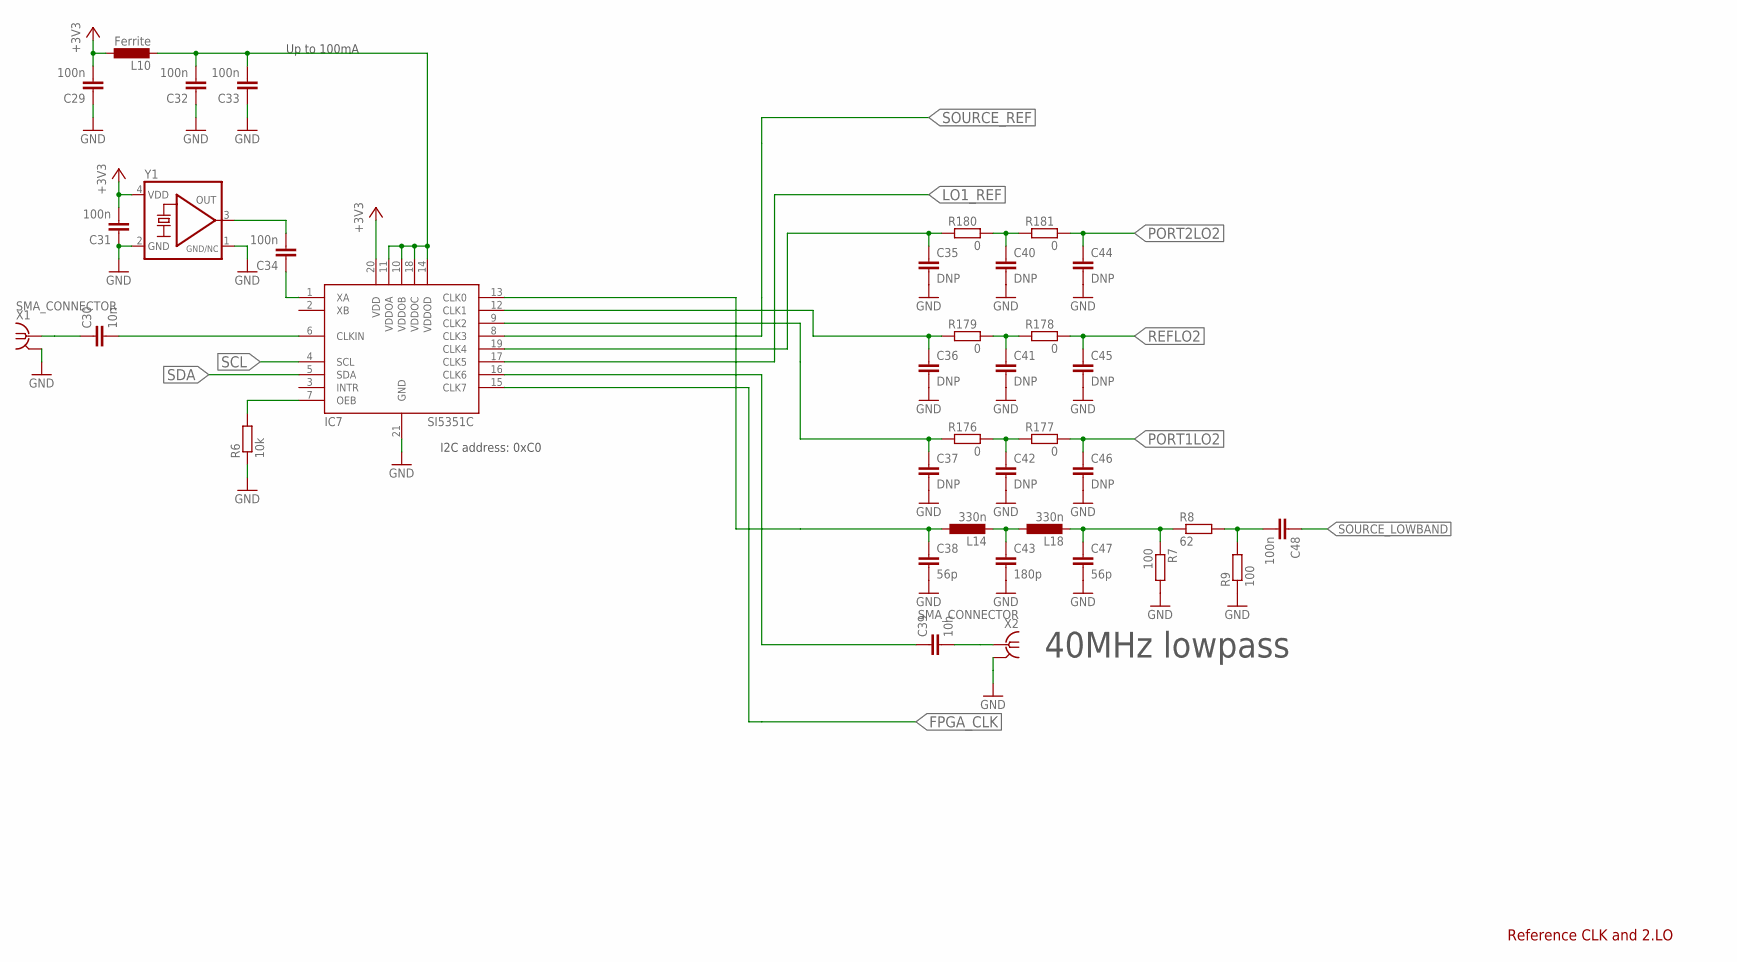
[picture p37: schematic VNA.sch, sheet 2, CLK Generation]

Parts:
C29, C31, C32, C33, C34, C48: 100n; C0402
C30, C39: 10n; C0402
C35, C36, C37, C40, C41, C42, C44, C45, C46: DNP; C0402
C38, C47: 56p; C0402
C43: 180p; C0402
IC7: SI5351C; QFN50P400X400X90-21T270N
L10: Ferrite; R0402
L14, L18: 330n; L0402
R6: 10k; R0402
R7, R9: 100; R0402
R8: 62; R0402
R176, R177, R178, R179, R180, R181: 0; R0402
X1, X2: SMA_CONNECTOR; J502-ND-142-0711-821/826
Y1: DSB221SDN/26MHz; 2.5X2.0_KXO-86-TCXO

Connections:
+3V3: C29.2, C31.2, IC7.20 (VDD), L10.1, Y1.4 (VDD); also elsewhere on the board
FPGA_CLK: IC7.15 (CLK7); also elsewhere on the board
GND: C29.1, C31.1, C32.1, C33.1, C35.2, C36.2, C37.2, C38.2, C40.2, C41.2, C42.2, C43.2, C44.2, C45.2, C46.2, C47.2, IC7.21 (GND), R6.1, R7.2, R9.1, X1.G@1 (2), X1.G@2 (2), X1.G@3 (2), X1.G@4 (2), X2.G@1 (2), X2.G@2 (2), X2.G@3 (2), X2.G@4 (2), Y1.1 (GND/NC), Y1.2 (GND); also elsewhere on the board
LO1_REF: IC7.17 (CLK5); also elsewhere on the board
unnamed: C43.1, L14.2, L18.1
unnamed: C39.2, X2.1
unnamed: C40.1, R180.2, R181.1
unnamed: C41.1, R178.1, R179.2
unnamed: C36.1, IC7.12 (CLK1), R179.1
unnamed: C42.1, R176.2, R177.1
unnamed: C35.1, IC7.19 (CLK4), R180.1
unnamed: C39.1, IC7.16 (CLK6)
unnamed: C30.1, X1.1
unnamed: C30.2, IC7.6 (CLKIN)
unnamed: C32.2, C33.2, IC7.10 (VDDOB), IC7.11 (VDDOA), IC7.14 (VDDOD), IC7.18 (VDDOC), L10.2
unnamed: IC7.7 (OEB), R6.2
unnamed: C34.2, Y1.3 (OUT)
unnamed: C34.1, IC7.1 (XA)
unnamed: C38.1, IC7.13 (CLK0), L14.1
unnamed: C48.2, R8.2, R9.2
unnamed: C37.1, IC7.9 (CLK2), R176.1
PORT1LO2: C46.1, R177.2; also elsewhere on the board
PORT2LO2: C44.1, R181.2; also elsewhere on the board
REFLO2: C45.1, R178.2; also elsewhere on the board
REFLO3: C47.1, L18.2, R7.1, R8.1
SCL: IC7.4 (SCL); also elsewhere on the board
SDA: IC7.5 (SDA); also elsewhere on the board
SOURCE_LOWBAND: C48.1; also elsewhere on the board
SOURCE_REF: IC7.8 (CLK3); also elsewhere on the board

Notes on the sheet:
Reference CLK and 2.LO
Up to 100mA
40MHz lowpass
I2C address: 0xC0

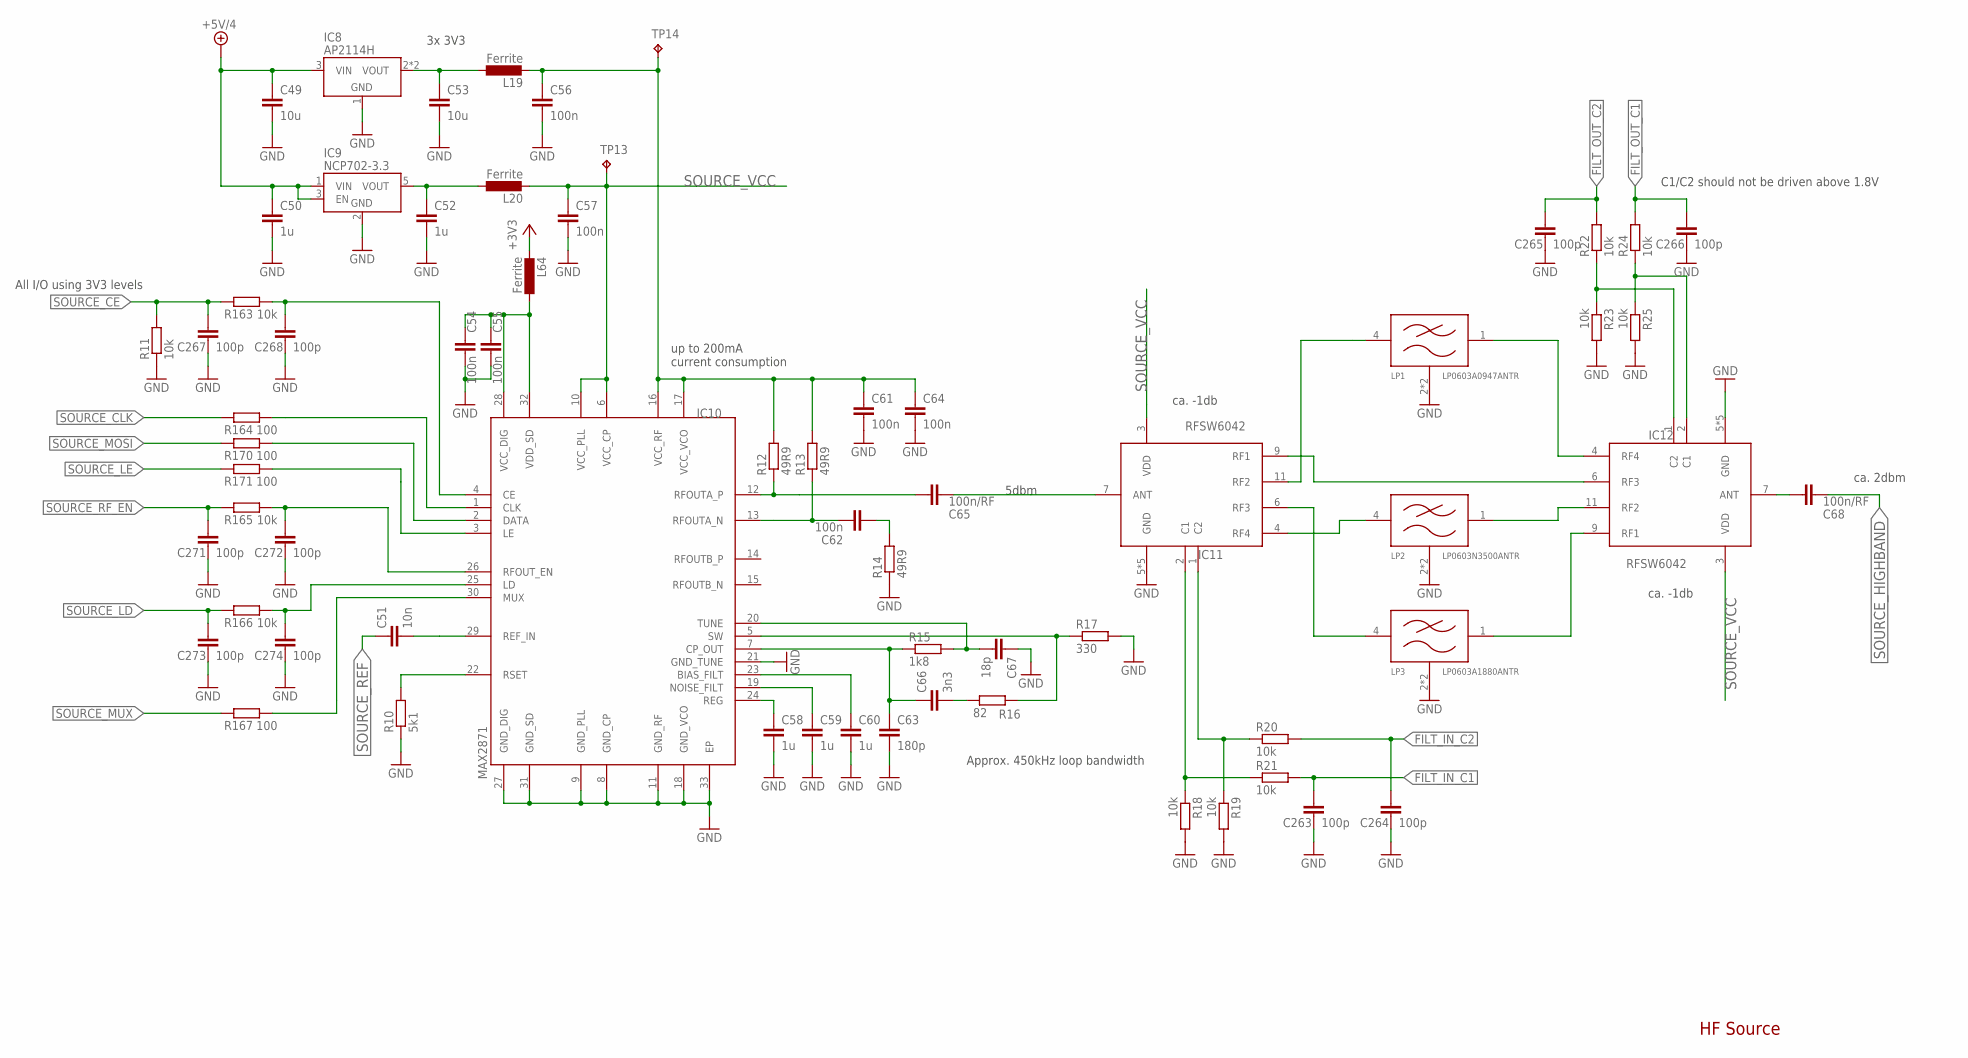
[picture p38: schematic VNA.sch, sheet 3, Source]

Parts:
C49, C53: 10u; C1206
C50, C52: 1u; C0603
C51: 10n; C0402
C54, C55, C56, C57, C61, C62, C64: 100n; C0402
C58, C59, C60: 1u; C0402
C63: 180p; C0402
C65, C68: 100n/RF; C0402
C66: 3n3; C0402
C67: 18p; C0402
C263, C264, C265, C266, C267, C268, C271, C272, C273, C274: 100p; C0402
IC8: AP2114H; SOT230P700X180-4
IC9: NCP702-3.3; SOT95P240X110-5
IC10: MAX2871; QFN50P500X500X80-33T310
IC11, IC12: RFSW6042; QFN40P180X180X55-13T76N
L19, L20, L64: Ferrite; R0402
LP1: LP0603A0947ANTR; FILTRDFN160X84X70-4N
LP2: LP0603N3500ANTR; FILTRDFN160X84X70-4N
LP3: LP0603A1880ANTR; FILTRDFN160X84X70-4N
R10: 5k1; R0402
R11, R18, R19, R20, R21, R22, R23, R24, R25, R163, R165, R166: 10k; R0402
R12, R13, R14: 49R9; R0402
R15: 1k8; R0402
R16: 82; R0402
R17: 330; R0402
R164, R167, R170, R171: 100; R0402
TP13, TP14: TPB1,27; B1,27

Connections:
+3V3: L64.2; also elsewhere on the board
+5V/4: C49.1, C50.1, IC8.3 (VIN), IC9.1 (VIN), IC9.3 (EN); also elsewhere on the board
FILT_IN_C1: C263.1, R21.2; also elsewhere on the board
FILT_IN_C2: C264.1, R20.2; also elsewhere on the board
FILT_OUT_C1: C266.1, R24.2; also elsewhere on the board
FILT_OUT_C2: C265.1, R22.2; also elsewhere on the board
GND: C49.2, C50.2, C52.2, C53.2, C54.2, C55.2, C56.2, C57.2, C58.2, C59.2, C60.2, C61.2, C63.2, C64.2, C67.1, C263.2, C264.2, C265.2, C266.2, C267.2, C268.2, C271.2, C272.2, C273.2, C274.2, IC8.1 (GND), IC9.2 (GND), IC10.8 (GND_CP), IC10.9 (GND_PLL), IC10.11 (GND_RF), IC10.18 (GND_VCO), IC10.21 (GND_TUNE), IC10.27 (GND_DIG), IC10.31 (GND_SD), IC10.33 (EP), IC11.5 (GND), IC11.8 (GND), IC11.10 (GND), IC11.12 (GND), IC11.13 (GND), IC12.5 (GND), IC12.8 (GND), IC12.10 (GND), IC12.12 (GND), IC12.13 (GND), LP1.2 (GND), LP1.3 (GND), LP2.2 (GND), LP2.3 (GND), LP3.2 (GND), LP3.3 (GND), R10.1, R11.1, R14.1, R17.2, R18.2, R19.2, R23.2, R25.2; also elsewhere on the board
unnamed: C67.2, IC10.20 (TUNE), R15.2
unnamed: C63.1, C66.1, IC10.7 (CP_OUT), R15.1
unnamed: C58.1, IC10.24 (REG)
unnamed: C59.1, IC10.19 (NOISE_FILT)
unnamed: C60.1, IC10.23 (BIAS_FILT)
unnamed: C66.2, R16.1
unnamed: IC10.5 (SW), R16.2, R17.1
unnamed: IC10.22 (RSET), R10.2
unnamed: C56.1, C61.1, C64.1, IC10.16 (VCC_RF), IC10.17 (VCC_VCO), L19.2, R12.2, R13.2, TP14.TP
unnamed: C51.2, IC10.29 (REF_IN)
unnamed: C65.1, IC10.12 (RFOUTA_P), R12.1
unnamed: C62.2, IC10.13 (RFOUTA_N), R13.1
unnamed: C62.1, R14.2
unnamed: C65.2, IC11.7 (ANT)
unnamed: IC11.9 (RF1), IC12.6 (RF3)
unnamed: IC11.11 (RF2), LP1.4 (IN)
unnamed: IC12.4 (RF4), LP1.1 (OUT)
unnamed: IC12.11 (RF2), LP2.1 (OUT)
unnamed: IC12.9 (RF1), LP3.1 (OUT)
unnamed: IC11.6 (RF3), LP3.4 (IN)
unnamed: IC11.4 (RF4), LP2.4 (IN)
unnamed: C53.1, IC8.2 (VOUT), IC8.4 (VOUT), L19.1
unnamed: C52.1, IC9.5 (VOUT), L20.1
unnamed: C68.1, IC12.7 (ANT)
unnamed: C268.1, IC10.4 (CE), R163.1
unnamed: IC11.2 (C1), R18.1, R21.1
unnamed: IC11.1 (C2), R19.1, R20.1
unnamed: IC12.1 (C2), R22.1, R23.1
unnamed: IC12.2 (C1), R24.1, R25.1
unnamed: IC10.1 (CLK), R164.1
unnamed: IC10.2 (DATA), R170.1
unnamed: IC10.3 (LE), R171.1
unnamed: IC10.30 (MUX), R167.1
unnamed: C272.1, IC10.26 (RFOUT_EN), R165.1
unnamed: C274.1, IC10.25 (LD), R166.1
unnamed: C54.1, C55.1, IC10.28 (VCC_DIG), IC10.32 (VDD_SD), L64.1
SOURCE_CE: C267.1, R11.2, R163.2; also elsewhere on the board
SOURCE_CLK: R164.2; also elsewhere on the board
SOURCE_HIGHBAND: C68.2; also elsewhere on the board
SOURCE_LD: C273.1, R166.2; also elsewhere on the board
SOURCE_LE: R171.2; also elsewhere on the board
SOURCE_MOSI: R170.2; also elsewhere on the board
SOURCE_MUX: R167.2; also elsewhere on the board
SOURCE_REF: C51.1; also elsewhere on the board
SOURCE_RF_EN: C271.1, R165.2; also elsewhere on the board
SOURCE_VCC: C57.1, IC10.6 (VCC_CP), IC10.10 (VCC_PLL), IC11.3 (VDD), IC12.3 (VDD), L20.2, TP13.TP

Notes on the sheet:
up to 200mA current consumption
All I/O using 3V3 levels
3x 3V3
Approx. 450kHz loop bandwidth
5dbm
ca. -1db
ca. 2dbm
C1/C2 should not be driven above 1.8V
HF Source

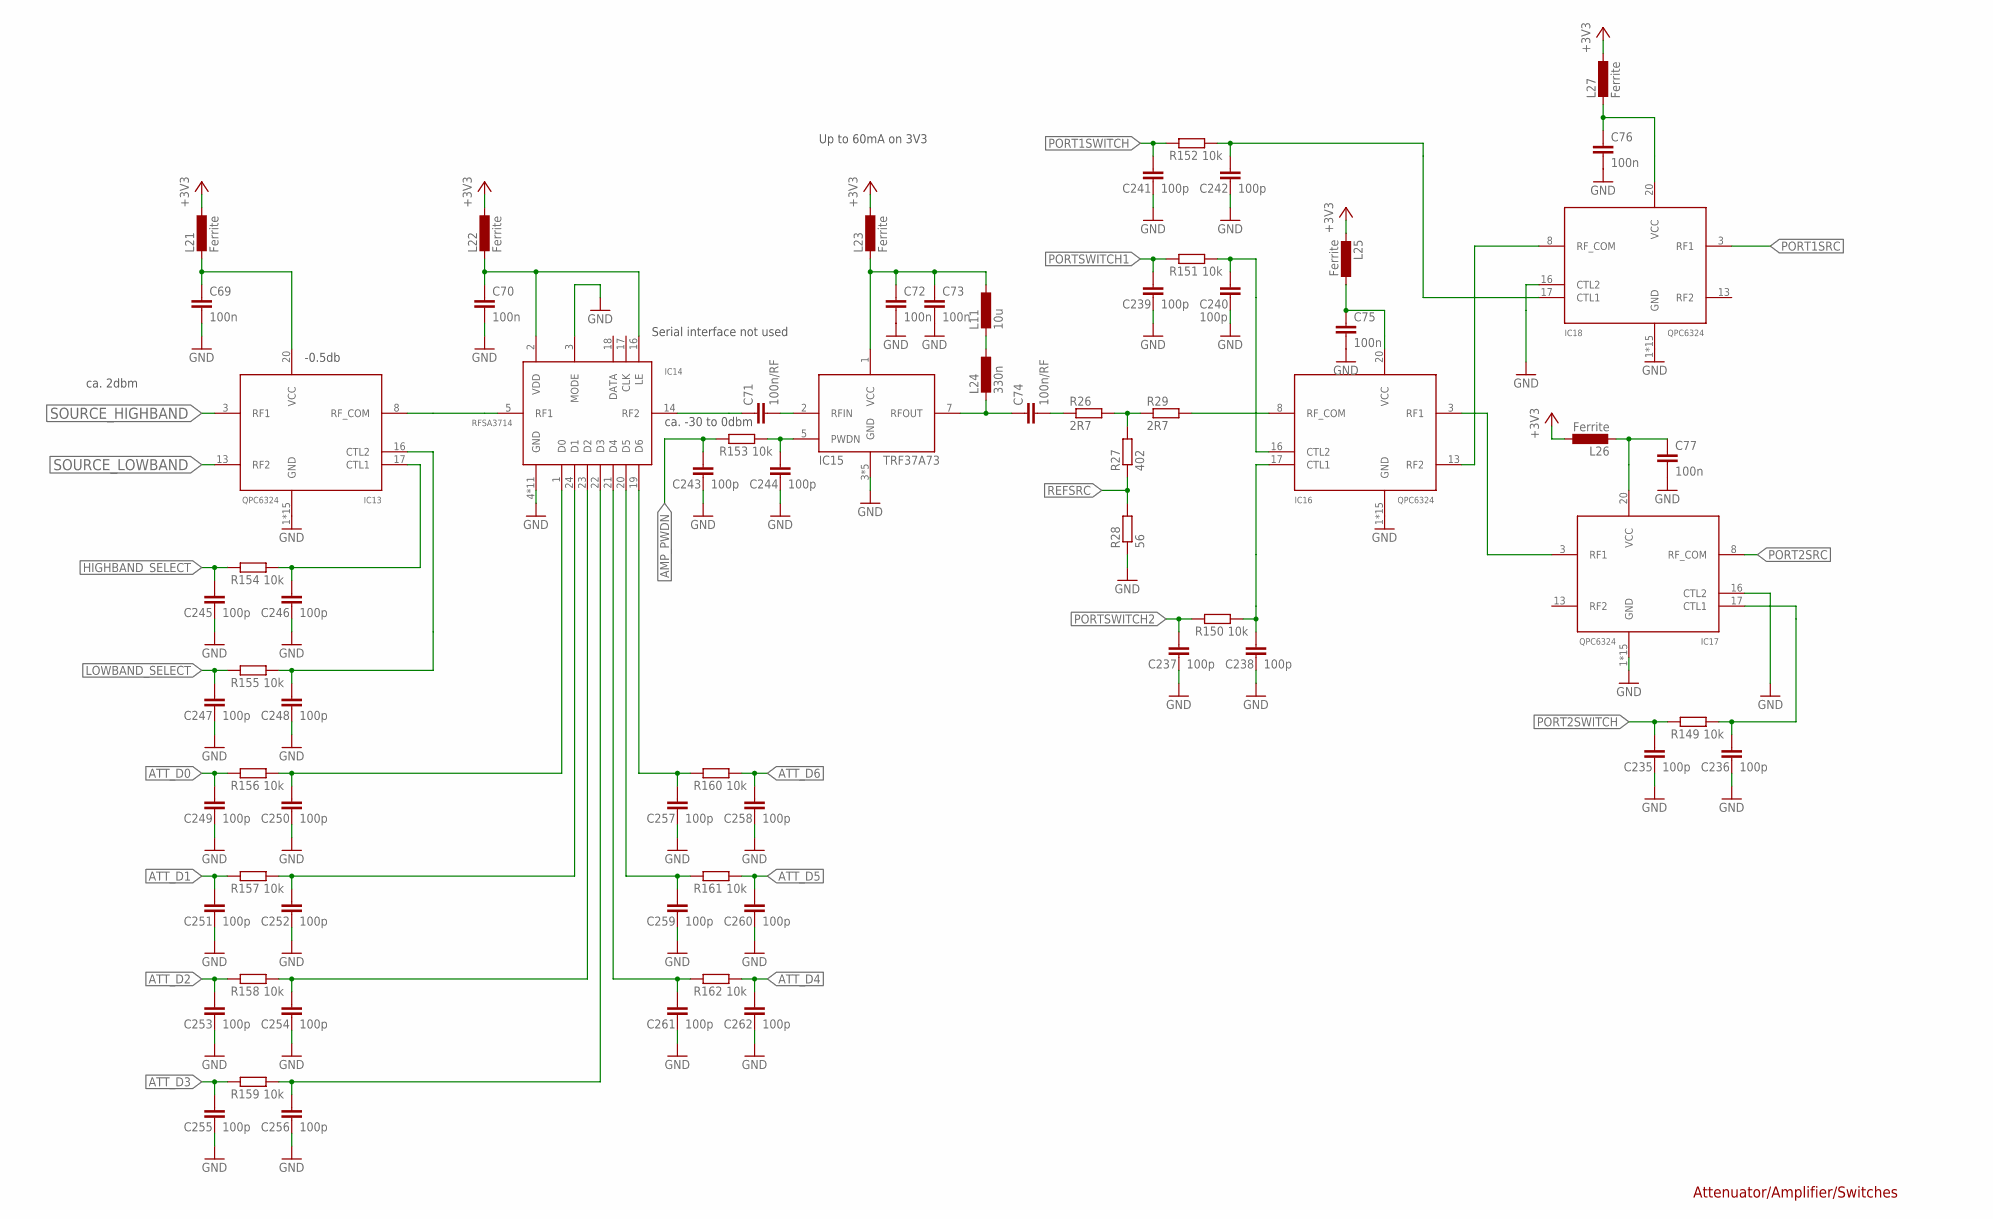
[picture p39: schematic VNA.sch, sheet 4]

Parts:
C69, C70, C72, C73, C75, C76, C77: 100n; C0402
C71, C74: 100n/RF; C0402
C235, C236, C237, C238, C239, C240, C241, C242, C243, C244, C245, C246, C247, C248, C249, C250, C251, C252, C253, C254, C255, C256, C257, C258, C259, C260, C261, C262: 100p; C0402
IC13, IC16, IC17, IC18: QPC6324; QFN50P400X400X75-21T206
IC14: RFSA3714; QFN50P400X400X75-25T270
IC15: TRF37A73; SON50P200X200X80-9T90X160N
L11: 10u; INDC2012X100N
L21, L22, L23, L25, L26, L27: Ferrite; R0402
L24: 330n; L0402
R26, R29: 2R7; R0402
R27: 402; R0402
R28: 56; R0402
R149, R150, R151, R152, R153, R154, R155, R156, R157, R158, R159, R160, R161, R162: 10k; R0402

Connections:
+3V3: L21.1, L22.1, L23.1, L25.2, L26.1, L27.1; also elsewhere on the board
AMP_PWDN: C243.1, R153.2; also elsewhere on the board
ATT_D0: C249.1, R156.2; also elsewhere on the board
ATT_D1: C251.1, R157.2; also elsewhere on the board
ATT_D2: C253.1, R158.2; also elsewhere on the board
ATT_D3: C255.1, R159.2; also elsewhere on the board
ATT_D4: C262.1, R162.1; also elsewhere on the board
ATT_D5: C260.1, R161.1; also elsewhere on the board
ATT_D6: C258.1, R160.1; also elsewhere on the board
GND: C69.2, C70.2, C72.2, C73.2, C75.2, C76.2, C77.2, C235.2, C236.2, C237.2, C238.2, C239.2, C240.2, C241.2, C242.2, C243.2, C244.2, C245.2, C246.2, C247.2, C248.2, C249.2, C250.2, C251.2, C252.2, C253.2, C254.2, C255.2, C256.2, C257.2, C258.2, C259.2, C260.2, C261.2, C262.2, IC13.1 (GND), IC13.2 (GND), IC13.4 (GND), IC13.5 (GND), IC13.6 (GND), IC13.7 (GND), IC13.9 (GND), IC13.10 (GND), IC13.11 (GND), IC13.12 (GND), IC13.14 (GND), IC13.15 (GND), IC13.18 (GND), IC13.19 (GND), IC13.21 (GND), IC14.3 (MODE), IC14.4 (GND), IC14.6 (GND), IC14.7 (GND), IC14.8 (GND), IC14.9 (GND), IC14.10 (GND), IC14.11 (GND), IC14.12 (GND), IC14.13 (GND), IC14.15 (GND), IC14.25 (GND), IC15.3 (GND), IC15.4 (GND), IC15.6 (GND), IC15.8 (GND), IC15.9 (GND), IC16.1 (GND), IC16.2 (GND), IC16.4 (GND), IC16.5 (GND), IC16.6 (GND), IC16.7 (GND), IC16.9 (GND), IC16.10 (GND), IC16.11 (GND), IC16.12 (GND), IC16.14 (GND), IC16.15 (GND), IC16.18 (GND), IC16.19 (GND), IC16.21 (GND), IC17.1 (GND), IC17.2 (GND), IC17.4 (GND), IC17.5 (GND), IC17.6 (GND), IC17.7 (GND), IC17.9 (GND), IC17.10 (GND), IC17.11 (GND), IC17.12 (GND), IC17.14 (GND), IC17.15 (GND), IC17.16 (CTL2), IC17.18 (GND), IC17.19 (GND), IC17.21 (GND), IC18.1 (GND), IC18.2 (GND), IC18.4 (GND), IC18.5 (GND), IC18.6 (GND), IC18.7 (GND), IC18.9 (GND), IC18.10 (GND), IC18.11 (GND), IC18.12 (GND), IC18.14 (GND), IC18.15 (GND), IC18.16 (CTL2), IC18.18 (GND), IC18.19 (GND), IC18.21 (GND), R28.1; also elsewhere on the board
HIGHBAND_SELECT: C245.1, R154.2; also elsewhere on the board
LOWBAND_SELECT: C247.1, R155.2; also elsewhere on the board
unnamed: C77.1, IC17.20 (VCC), L26.2
unnamed: C69.1, IC13.20 (VCC), L21.2
unnamed: IC13.8 (RF_COM), IC14.5 (RF1)
unnamed: C70.1, IC14.2 (VDD), IC14.16 (LE), L22.2
unnamed: C71.1, IC14.14 (RF2)
unnamed: C71.2, IC15.2 (RFIN)
unnamed: C74.1, IC15.7 (RFOUT), L24.2
unnamed: C74.2, R26.1
unnamed: IC16.8 (RF_COM), R29.2
unnamed: C72.1, C73.1, IC15.1 (VCC), L11.1, L23.2
unnamed: R26.2, R27.2, R29.1
unnamed: IC16.13 (RF2), IC18.8 (RF_COM)
unnamed: IC16.3 (RF1), IC17.3 (RF1)
unnamed: C76.1, IC18.20 (VCC), L27.2
unnamed: C236.1, IC17.17 (CTL1), R149.1
unnamed: C240.1, IC16.16 (CTL2), R151.1
unnamed: C238.1, IC16.17 (CTL1), R150.1
unnamed: C242.1, IC18.17 (CTL1), R152.1
unnamed: C244.1, IC15.5 (PWDN), R153.1
unnamed: C246.1, IC13.17 (CTL1), R154.1
unnamed: C250.1, IC14.1 (D0), R156.1
unnamed: C248.1, IC13.16 (CTL2), R155.1
unnamed: C252.1, IC14.24 (D1), R157.1
unnamed: C75.1, IC16.20 (VCC), L25.1
unnamed: C254.1, IC14.23 (D2), R158.1
unnamed: C256.1, IC14.22 (D3), R159.1
unnamed: C257.1, IC14.19 (D6), R160.2
unnamed: C259.1, IC14.20 (D5), R161.2
unnamed: C261.1, IC14.21 (D4), R162.2
unnamed: L11.2, L24.1
PORT1SRC: IC18.3 (RF1); also elsewhere on the board
PORT1SWITCH: C241.1, R152.2; also elsewhere on the board
PORT2SRC: IC17.8 (RF_COM); also elsewhere on the board
PORT2SWITCH: C235.1, R149.2; also elsewhere on the board
PORTSWITCH1: C239.1, R151.2; also elsewhere on the board
PORTSWITCH2: C237.1, R150.2; also elsewhere on the board
REFSRC: R27.1, R28.2; also elsewhere on the board
SOURCE_HIGHBAND: IC13.3 (RF1); also elsewhere on the board
SOURCE_LOWBAND: IC13.13 (RF2); also elsewhere on the board

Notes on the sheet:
Serial interface not used
ca. 2dbm
-0.5db
ca. -30 to 0dbm
Up to 60mA on 3V3
Attenuator/Amplifier/Switches

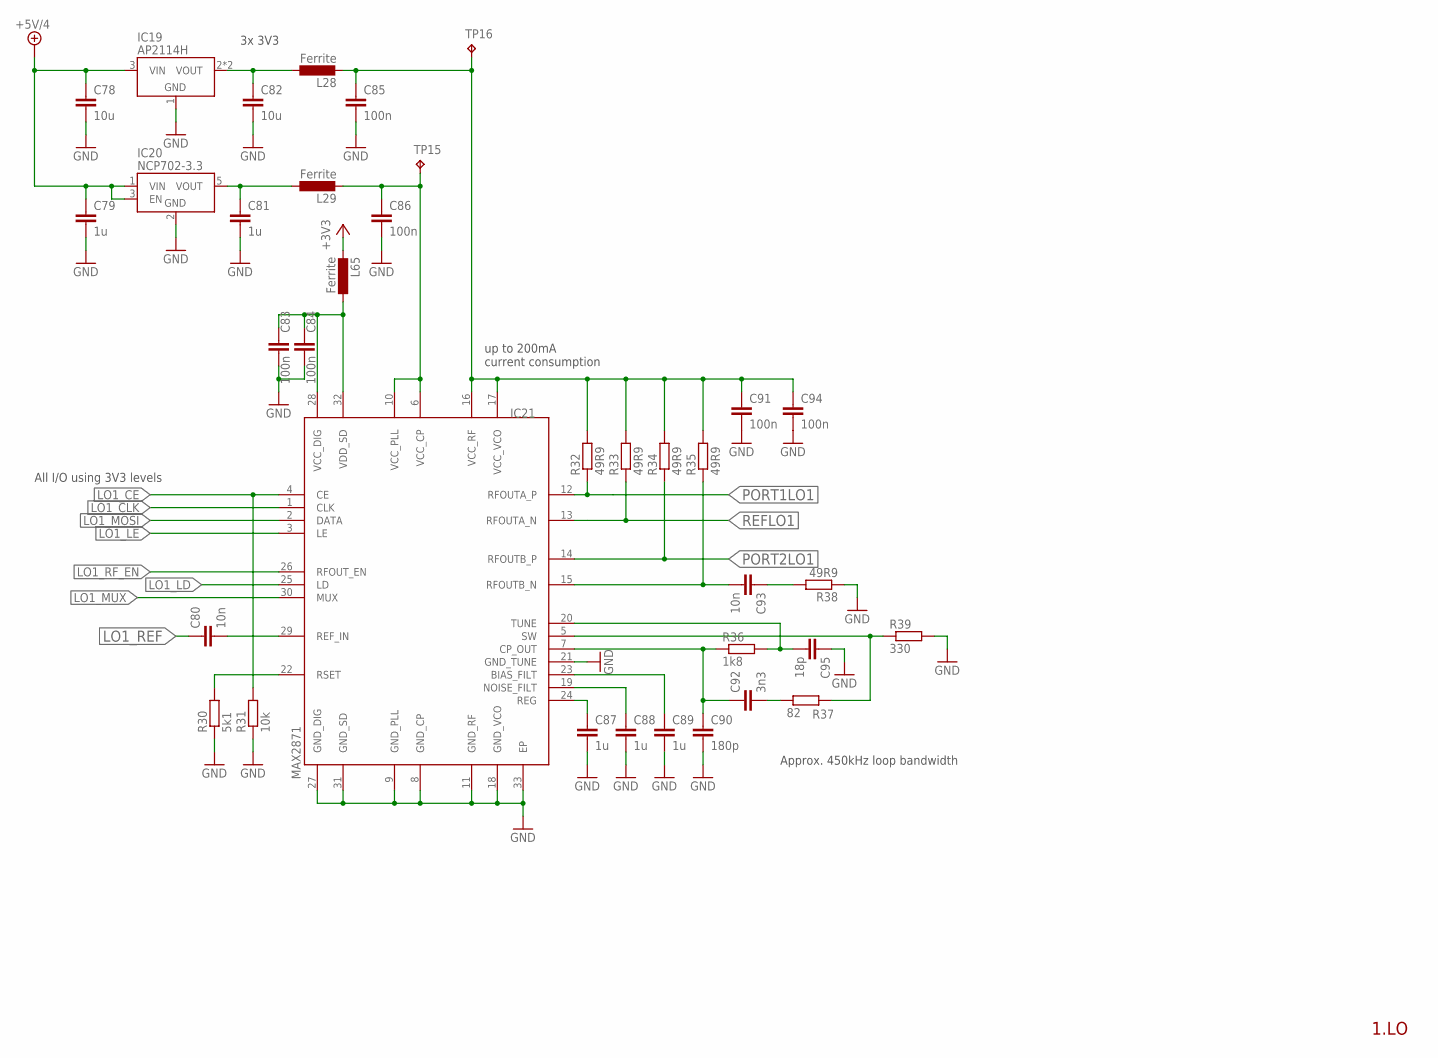
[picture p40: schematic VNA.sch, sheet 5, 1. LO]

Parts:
C78, C82: 10u; C1206
C79, C81: 1u; C0603
C80, C93: 10n; C0402
C83, C84, C85, C86, C91, C94: 100n; C0402
C87, C88, C89: 1u; C0402
C90: 180p; C0402
C92: 3n3; C0402
C95: 18p; C0402
IC19: AP2114H; SOT230P700X180-4
IC20: NCP702-3.3; SOT95P240X110-5
IC21: MAX2871; QFN50P500X500X80-33T310
L28, L29, L65: Ferrite; R0402
R30: 5k1; R0402
R31: 10k; R0402
R32, R33, R34, R35, R38: 49R9; R0402
R36: 1k8; R0402
R37: 82; R0402
R39: 330; R0402
TP15, TP16: TPB1,27; B1,27

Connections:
+3V3: L65.2; also elsewhere on the board
+5V/4: C78.1, C79.1, IC19.3 (VIN), IC20.1 (VIN), IC20.3 (EN); also elsewhere on the board
GND: C78.2, C79.2, C81.2, C82.2, C83.2, C84.2, C85.2, C86.2, C87.2, C88.2, C89.2, C90.2, C91.2, C94.2, C95.1, IC19.1 (GND), IC20.2 (GND), IC21.8 (GND_CP), IC21.9 (GND_PLL), IC21.11 (GND_RF), IC21.18 (GND_VCO), IC21.21 (GND_TUNE), IC21.27 (GND_DIG), IC21.31 (GND_SD), IC21.33 (EP), R30.1, R31.1, R38.1, R39.2; also elsewhere on the board
LO1_CE: IC21.4 (CE), R31.2; also elsewhere on the board
LO1_CLK: IC21.1 (CLK); also elsewhere on the board
LO1_LD: IC21.25 (LD); also elsewhere on the board
LO1_LE: IC21.3 (LE); also elsewhere on the board
LO1_MOSI: IC21.2 (DATA); also elsewhere on the board
LO1_MUX: IC21.30 (MUX); also elsewhere on the board
LO1_REF: C80.1; also elsewhere on the board
LO1_RF_EN: IC21.26 (RFOUT_EN); also elsewhere on the board
unnamed: C86.1, IC21.6 (VCC_CP), IC21.10 (VCC_PLL), L29.2, TP15.TP
unnamed: C95.2, IC21.20 (TUNE), R36.2
unnamed: C90.1, C92.1, IC21.7 (CP_OUT), R36.1
unnamed: C87.1, IC21.24 (REG)
unnamed: C88.1, IC21.19 (NOISE_FILT)
unnamed: C89.1, IC21.23 (BIAS_FILT)
unnamed: C92.2, R37.1
unnamed: IC21.5 (SW), R37.2, R39.1
unnamed: IC21.22 (RSET), R30.2
unnamed: C85.1, C91.1, C94.1, IC21.16 (VCC_RF), IC21.17 (VCC_VCO), L28.2, R32.2, R33.2, R34.2, R35.2, TP16.TP
unnamed: C80.2, IC21.29 (REF_IN)
unnamed: C93.1, R38.2
unnamed: C82.1, IC19.2 (VOUT), IC19.4 (VOUT), L28.1
unnamed: C81.1, IC20.5 (VOUT), L29.1
unnamed: C93.2, IC21.15 (RFOUTB_N), R35.1
unnamed: C83.1, C84.1, IC21.28 (VCC_DIG), IC21.32 (VDD_SD), L65.1
PORT1LO1: IC21.12 (RFOUTA_P), R32.1; also elsewhere on the board
PORT2LO1: IC21.14 (RFOUTB_P), R34.1; also elsewhere on the board
REFLO1: IC21.13 (RFOUTA_N), R33.1; also elsewhere on the board

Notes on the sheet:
up to 200mA current consumption
All I/O using 3V3 levels
3x 3V3
Approx. 450kHz loop bandwidth
1.LO

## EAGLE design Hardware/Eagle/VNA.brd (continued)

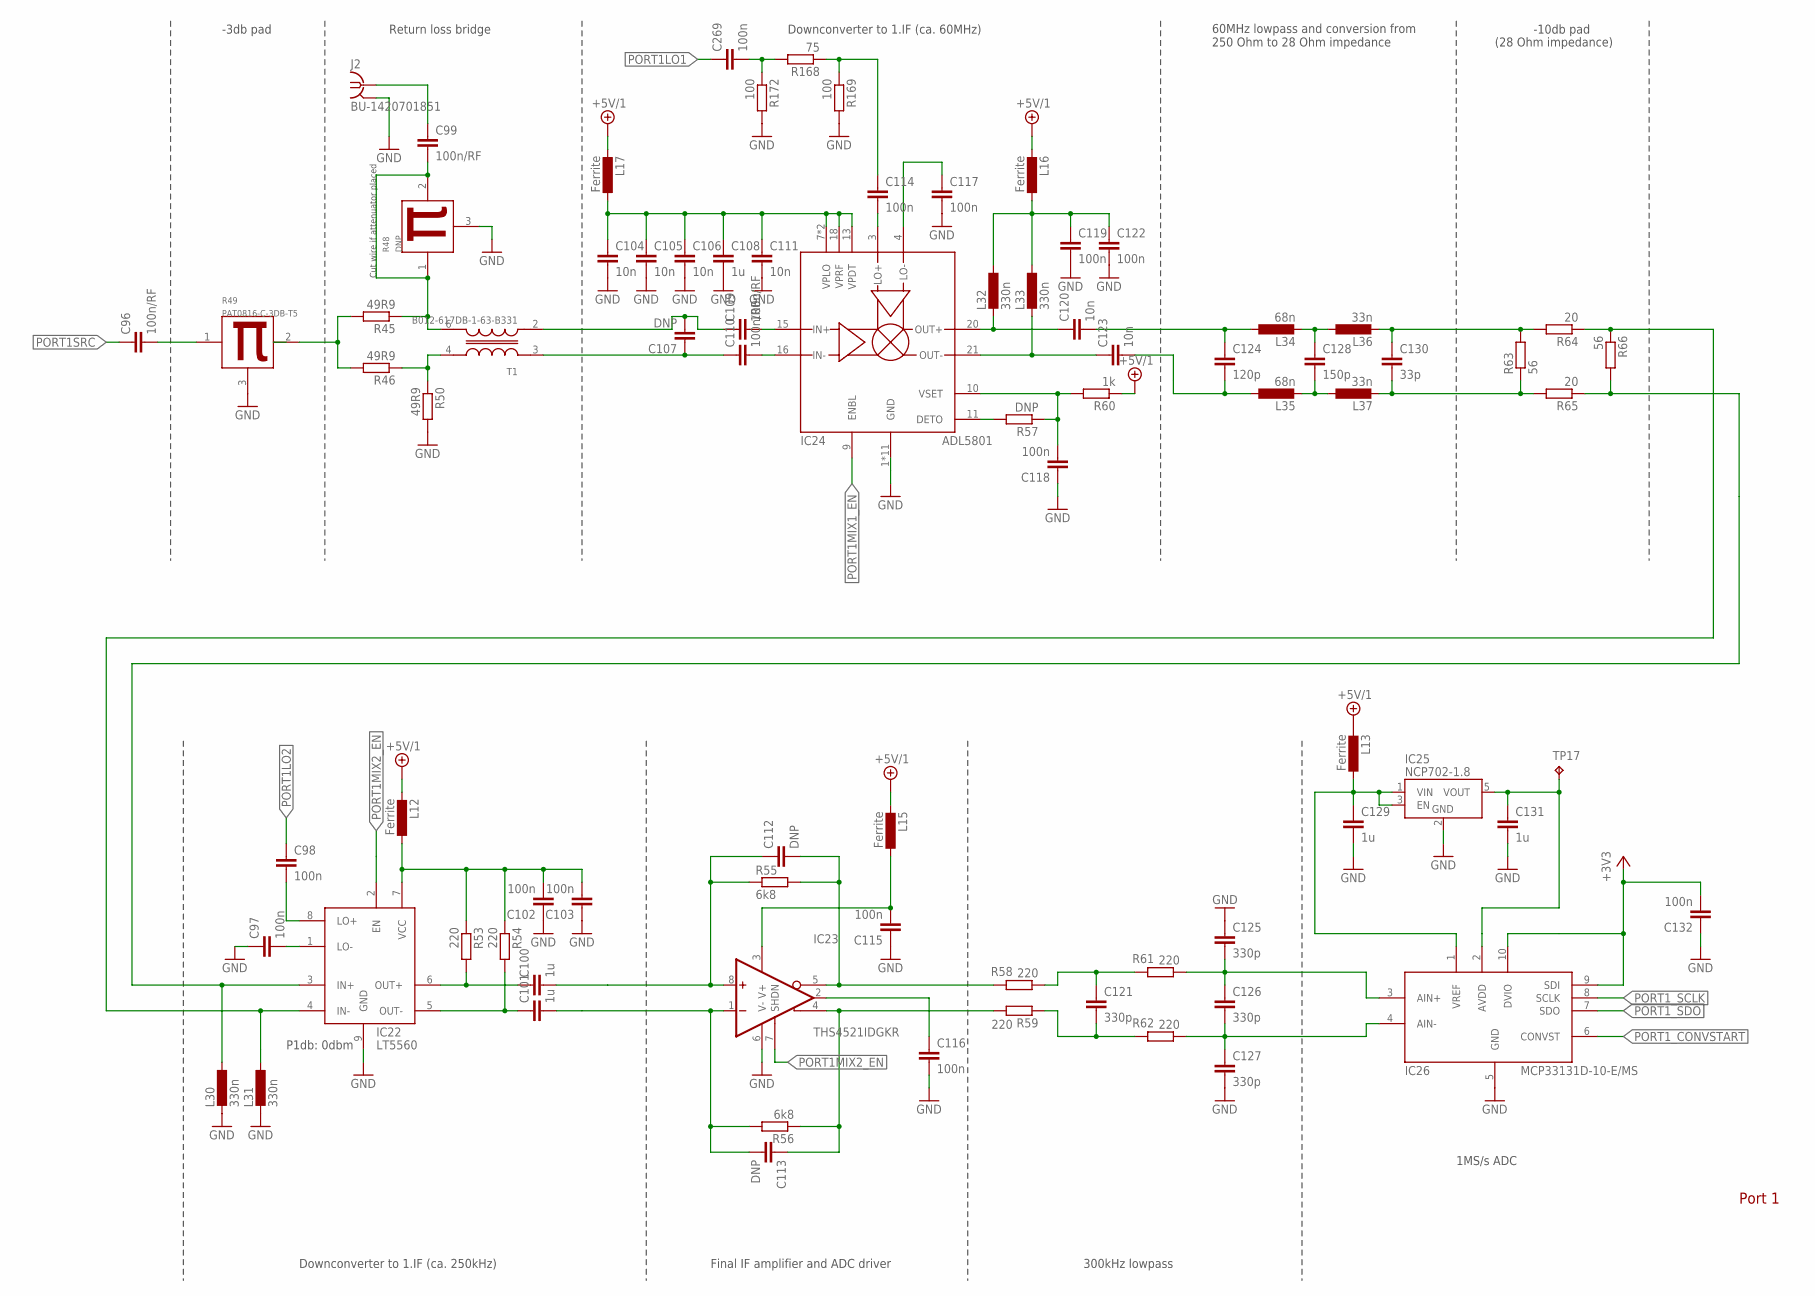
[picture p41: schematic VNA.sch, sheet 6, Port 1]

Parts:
C96, C99, C109, C110: 100n/RF; C0402
C97, C98, C102, C103, C114, C115, C116, C117, C118, C119, C122, C132, C269: 100n; C0402
C100, C101, C108, C129, C131: 1u; C0402
C104, C105, C106, C111, C120, C123: 10n; C0402
C107, C112, C113: DNP; C0402
C121, C125, C126, C127: 330p; C0402
C124: 120p; C0402
C128: 150p; C0402
C130: 33p; C0402
IC22: LT5560; SON50P300X300X80-9T165X238
IC23: THS4521IDGKR; SOP65P490X110-8N
IC24: ADL5801; QFN50P400X400X100-25T250N
IC25: NCP702-1.8; SOT95P240X110-5
IC26: MCP33131D-10-E/MS; SOP50P490X110-10N
J2: BU-1420701851
L12, L13, L15, L16, L17: Ferrite; R0402
L30, L31, L32, L33: 330n; L0402
L34, L35: 68n; L0402
L36, L37: 33n; L0402
R45, R46, R50: 49R9; R0402
R48: DNP; PAT0816
R49: PAT0816-C-3DB-T5; PAT0816
R53, R54, R58, R59, R61, R62: 220; R0402
R55, R56: 6k8; R0402
R57: DNP; R0402
R60: 1k; R0402
R63, R66: 56; R0402
R64, R65: 20; R0402
R168: 75; R0402
R169, R172: 100; R0402
T1: B012-617DB-1-63-B331; EASTEVER_BALUN
TP17: TPB1,27; B1,27

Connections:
+3V3: C132.2, IC26.9 (SDI), IC26.10 (DVIO); also elsewhere on the board
+5V/1: L12.2, L13.2, L15.2, L16.2, L17.2, R60.1; also elsewhere on the board
GND: C97.1, C102.1, C103.1, C104.2, C105.2, C106.2, C108.2, C111.2, C115.1, C116.2, C117.2, C118.1, C119.2, C122.2, C125.1, C127.2, C129.2, C131.2, C132.1, IC22.9 (GND), IC23.6 (V-), IC24.1 (GND), IC24.2 (GND), IC24.5 (GND), IC24.6 (GND), IC24.8 (GND), IC24.12 (GND), IC24.14 (GND), IC24.17 (GND), IC24.19 (GND), IC24.23 (GND), IC24.25 (GND), IC25.2 (GND), IC26.5 (GND), J2.G@1 (2), J2.G@2 (2), J2.G@3 (2), J2.G@4 (2), L30.2, L31.2, R48.3 (GND), R49.3 (GND), R50.2, R169.2, R172.2; also elsewhere on the board
unnamed: C96.2, R49.1 (IN)
unnamed: R45.2, R46.2, R49.2 (OUT)
unnamed: C120.2, C124.1, L34.1
unnamed: R46.1, R50.1, T1.4 (OUT+)
unnamed: C99.1, J2.1
unnamed: C109.2, IC24.15 (IN+)
unnamed: C110.2, IC24.16 (IN-)
unnamed: C107.1, C110.1, T1.3 (IN+)
unnamed: C107.2, C109.1, T1.2 (IN-)
unnamed: C117.1, IC24.4 (LO-)
unnamed: C114.2, IC24.3 (LO+)
unnamed: C125.2, C126.1, IC26.3 (AIN+), R61.1
unnamed: C120.1, IC24.20 (OUT+), L32.2
unnamed: C123.1, IC24.21 (OUT-), L33.2
unnamed: C123.2, C124.2, L35.1
unnamed: C128.2, L35.2, L37.1
unnamed: C98.2, IC22.8 (LO+)
unnamed: C118.2, IC24.10 (VSET), R57.1, R60.2
unnamed: C126.2, C127.1, IC26.4 (AIN-), R62.1
unnamed: C97.2, IC22.1 (LO-)
unnamed: C102.2, C103.2, IC22.7 (VCC), L12.1, R53.1, R54.1
unnamed: C100.1, IC22.6 (OUT+), R53.2
unnamed: C101.1, IC22.5 (OUT-), R54.2
unnamed: C113.1, IC23.4 (+OUT), R56.1, R59.2
unnamed: C112.2, IC23.5 (-OUT), R55.2, R58.2
unnamed: C128.1, L34.2, L36.1
unnamed: C130.1, L36.2, R63.2, R64.2
unnamed: C130.2, L37.2, R63.1, R65.2
unnamed: C101.2, C113.2, IC23.1 (-IN), R56.2
unnamed: C100.2, C112.1, IC23.8 (+IN), R55.1
unnamed: C131.1, IC25.5 (VOUT), IC26.2 (AVDD), TP17.TP
unnamed: IC22.4 (IN-), L31.1, R64.1, R66.1
unnamed: IC22.3 (IN+), L30.1, R65.1, R66.2
unnamed: IC24.11 (DETO), R57.2
unnamed: C129.1, IC25.1 (VIN), IC25.3 (EN), IC26.1 (VREF), L13.1
unnamed: C119.1, C122.1, L16.1, L32.1, L33.1
unnamed: C269.2, R168.2, R172.1
unnamed: C114.1, R168.1, R169.1
unnamed: C99.2, R45.1, R48.1 (IN), R48.2 (OUT), T1.6 (OUT-)
unnamed: C115.2, IC23.3 (V+), L15.1
unnamed: C104.1, C105.1, C106.1, C108.1, C111.1, IC24.7 (VPLO), IC24.13 (VPDT), IC24.18 (VPRF), IC24.24 (VPLO), L17.1
OUT+: C121.1, R58.1, R61.2
OUT-: C121.2, R59.1, R62.2
OUT_CM: C116.1, IC23.2 (VOCM)
PORT1LO1: C269.1; also elsewhere on the board
PORT1LO2: C98.1; also elsewhere on the board
PORT1MIX1_EN: IC24.9 (ENBL); also elsewhere on the board
PORT1MIX2_EN: IC22.2 (EN), IC23.7 (SHDN); also elsewhere on the board
PORT1SRC: C96.1; also elsewhere on the board
PORT1_CONVSTART: IC26.6 (CONVST); also elsewhere on the board
PORT1_SCLK: IC26.8 (SCLK); also elsewhere on the board
PORT1_SDO: IC26.7 (SDO); also elsewhere on the board

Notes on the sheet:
P1db: 0dbm
-3db pad
Return loss bridge
Downconverter to 1.IF (ca. 60MHz)
60MHz lowpass and conversion from 250 Ohm to 28 Ohm impedance
-10db pad
(28 Ohm impedance)
Downconverter to 1.IF (ca. 250kHz)
Final IF amplifier and ADC driver
300kHz lowpass
1MS/s ADC
Port 1
Cut wire if attenuator placed

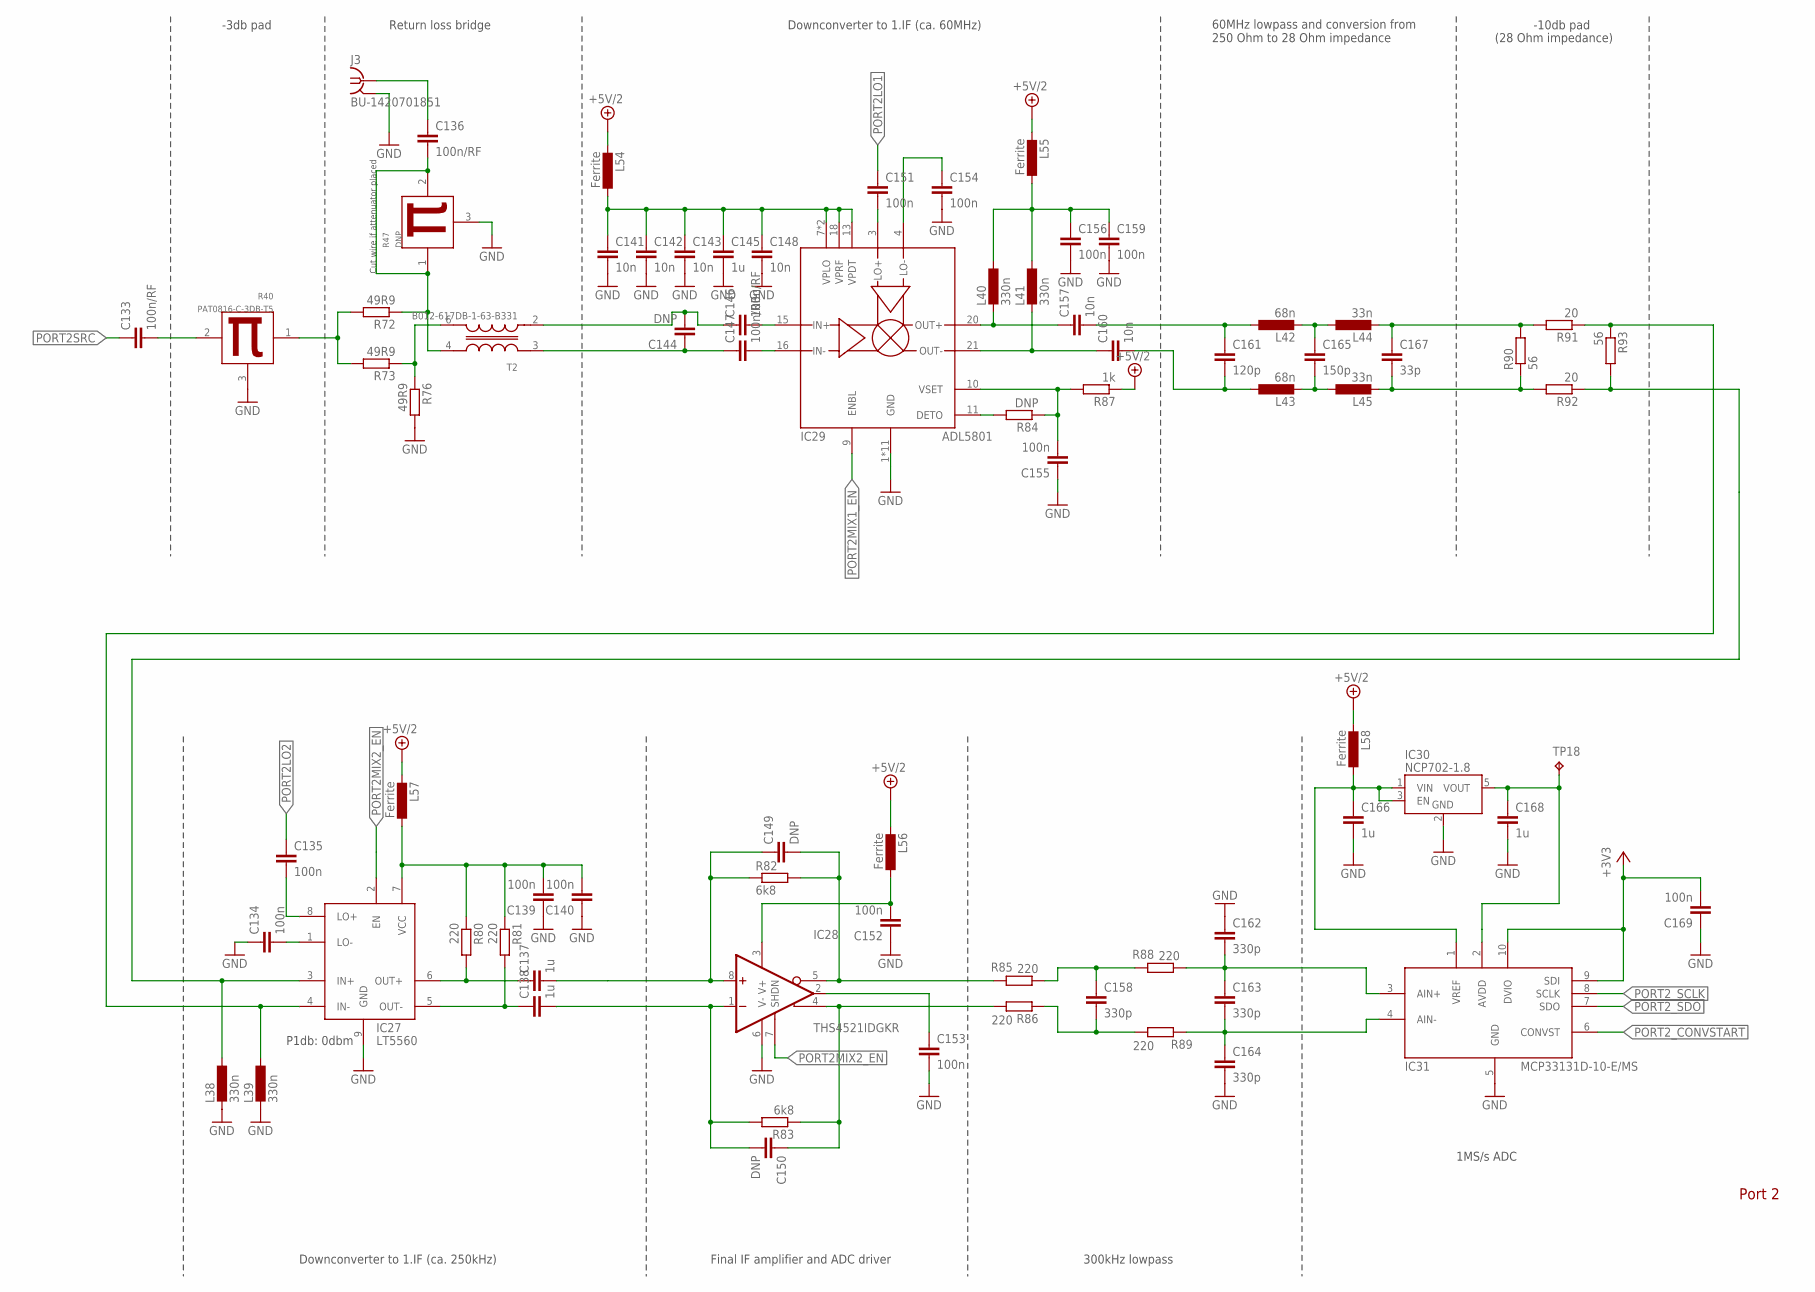
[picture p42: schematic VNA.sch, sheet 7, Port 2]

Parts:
C133, C136, C146, C147: 100n/RF; C0402
C134, C135, C139, C140, C151, C152, C153, C154, C155, C156, C159, C169: 100n; C0402
C137, C138, C145, C166, C168: 1u; C0402
C141, C142, C143, C148, C157, C160: 10n; C0402
C144, C149, C150: DNP; C0402
C158, C162, C163, C164: 330p; C0402
C161: 120p; C0402
C165: 150p; C0402
C167: 33p; C0402
IC27: LT5560; SON50P300X300X80-9T165X238
IC28: THS4521IDGKR; SOP65P490X110-8N
IC29: ADL5801; QFN50P400X400X100-25T250N
IC30: NCP702-1.8; SOT95P240X110-5
IC31: MCP33131D-10-E/MS; SOP50P490X110-10N
J3: BU-1420701851
L38, L39, L40, L41: 330n; L0402
L42, L43: 68n; L0402
L44, L45: 33n; L0402
L54, L55, L56, L57, L58: Ferrite; R0402
R40: PAT0816-C-3DB-T5; PAT0816
R47: DNP; PAT0816
R72, R73, R76: 49R9; R0402
R80, R81, R85, R86, R88, R89: 220; R0402
R82, R83: 6k8; R0402
R84: DNP; R0402
R87: 1k; R0402
R90, R93: 56; R0402
R91, R92: 20; R0402
T2: B012-617DB-1-63-B331; EASTEVER_BALUN
TP18: TPB1,27; B1,27

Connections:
+3V3: C169.2, IC31.9 (SDI), IC31.10 (DVIO); also elsewhere on the board
+5V/2: L54.2, L55.2, L56.2, L57.2, L58.2, R87.1; also elsewhere on the board
GND: C134.1, C139.1, C140.1, C141.2, C142.2, C143.2, C145.2, C148.2, C152.1, C153.2, C154.2, C155.1, C156.2, C159.2, C162.1, C164.2, C166.2, C168.2, C169.1, IC27.9 (GND), IC28.6 (V-), IC29.1 (GND), IC29.2 (GND), IC29.5 (GND), IC29.6 (GND), IC29.8 (GND), IC29.12 (GND), IC29.14 (GND), IC29.17 (GND), IC29.19 (GND), IC29.23 (GND), IC29.25 (GND), IC30.2 (GND), IC31.5 (GND), J3.G@1 (2), J3.G@2 (2), J3.G@3 (2), J3.G@4 (2), L38.2, L39.2, R40.3 (GND), R47.3 (GND), R76.2; also elsewhere on the board
unnamed: C136.2, R47.1 (IN), R47.2 (OUT), R72.1, T2.4 (OUT+)
unnamed: C133.2, R40.2 (OUT)
unnamed: R40.1 (IN), R72.2, R73.2
unnamed: IC27.3 (IN+), L38.1, R92.1, R93.2
unnamed: R73.1, R76.1, T2.6 (OUT-)
unnamed: C146.2, IC29.15 (IN+)
unnamed: C147.2, IC29.16 (IN-)
unnamed: C144.1, C147.1, T2.3 (IN+)
unnamed: C144.2, C146.1, T2.2 (IN-)
unnamed: C154.1, IC29.4 (LO-)
unnamed: C151.2, IC29.3 (LO+)
unnamed: C157.1, IC29.20 (OUT+), L40.2
unnamed: C160.1, IC29.21 (OUT-), L41.2
unnamed: C155.2, IC29.10 (VSET), R84.1, R87.2
unnamed: C134.2, IC27.1 (LO-)
unnamed: C137.1, IC27.6 (OUT+), R80.2
unnamed: C138.1, IC27.5 (OUT-), R81.2
unnamed: C150.1, IC28.4 (+OUT), R83.1, R86.2
unnamed: C149.2, IC28.5 (-OUT), R82.2, R85.2
unnamed: C157.2, C161.1, L42.1
unnamed: C160.2, C161.2, L43.1
unnamed: C165.2, L43.2, L45.1
unnamed: C165.1, L42.2, L44.1
unnamed: C135.2, IC27.8 (LO+)
unnamed: C162.2, C163.1, IC31.3 (AIN+), R88.1
unnamed: C163.2, C164.1, IC31.4 (AIN-), R89.1
unnamed: C167.1, L44.2, R90.2, R91.2
unnamed: C167.2, L45.2, R90.1, R92.2
unnamed: C138.2, C150.2, IC28.1 (-IN), R83.2
unnamed: C137.2, C149.1, IC28.8 (+IN), R82.1
unnamed: C168.1, IC30.5 (VOUT), IC31.2 (AVDD), TP18.TP
unnamed: IC27.4 (IN-), L39.1, R91.1, R93.1
unnamed: IC29.11 (DETO), R84.2
unnamed: C136.1, J3.1
unnamed: C141.1, C142.1, C143.1, C145.1, C148.1, IC29.7 (VPLO), IC29.13 (VPDT), IC29.18 (VPRF), IC29.24 (VPLO), L54.1
unnamed: C156.1, C159.1, L40.1, L41.1, L55.1
unnamed: C152.2, IC28.3 (V+), L56.1
unnamed: C139.2, C140.2, IC27.7 (VCC), L57.1, R80.1, R81.1
unnamed: C166.1, IC30.1 (VIN), IC30.3 (EN), IC31.1 (VREF), L58.1
OUT+1: C158.1, R85.1, R88.2
OUT-1: C158.2, R86.1, R89.2
OUT_CM1: C153.1, IC28.2 (VOCM)
PORT2LO1: C151.1; also elsewhere on the board
PORT2LO2: C135.1; also elsewhere on the board
PORT2MIX1_EN: IC29.9 (ENBL); also elsewhere on the board
PORT2MIX2_EN: IC27.2 (EN), IC28.7 (SHDN); also elsewhere on the board
PORT2SRC: C133.1; also elsewhere on the board
PORT2_CONVSTART: IC31.6 (CONVST); also elsewhere on the board
PORT2_SCLK: IC31.8 (SCLK); also elsewhere on the board
PORT2_SDO: IC31.7 (SDO); also elsewhere on the board

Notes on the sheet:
P1db: 0dbm
-3db pad
Return loss bridge
Downconverter to 1.IF (ca. 60MHz)
60MHz lowpass and conversion from 250 Ohm to 28 Ohm impedance
-10db pad
(28 Ohm impedance)
Downconverter to 1.IF (ca. 250kHz)
Final IF amplifier and ADC driver
300kHz lowpass
1MS/s ADC
Port 2
Cut wire if attenuator placed

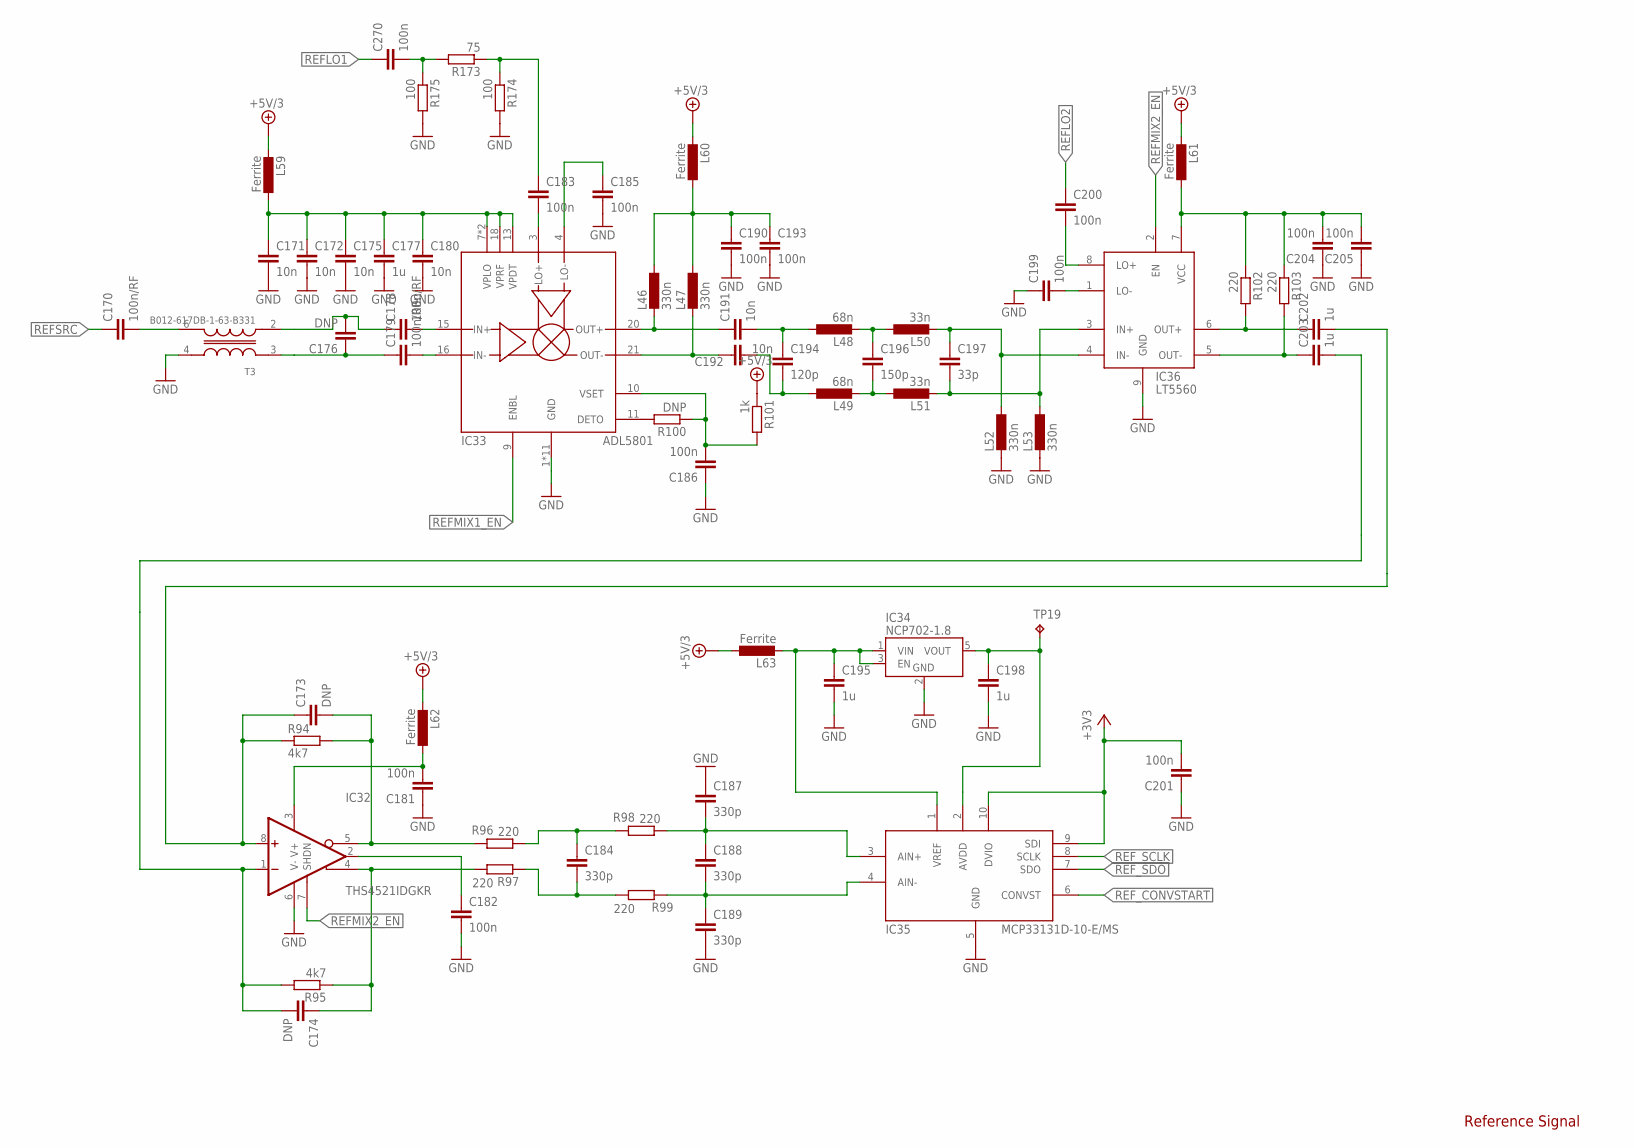
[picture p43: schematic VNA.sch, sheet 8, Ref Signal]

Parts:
C170, C178, C179: 100n/RF; C0402
C171, C172, C175, C180, C191, C192: 10n; C0402
C173, C174, C176: DNP; C0402
C177, C195, C198, C202, C203: 1u; C0402
C181, C182, C183, C185, C186, C190, C193, C199, C200, C201, C204, C205, C270: 100n; C0402
C184, C187, C188, C189: 330p; C0402
C194: 120p; C0402
C196: 150p; C0402
C197: 33p; C0402
IC32: THS4521IDGKR; SOP65P490X110-8N
IC33: ADL5801; QFN50P400X400X100-25T250N
IC34: NCP702-1.8; SOT95P240X110-5
IC35: MCP33131D-10-E/MS; SOP50P490X110-10N
IC36: LT5560; SON50P300X300X80-9T165X238
L46, L47, L52, L53: 330n; L0402
L48, L49: 68n; L0402
L50, L51: 33n; L0402
L59, L60, L61, L62, L63: Ferrite; R0402
R94, R95: 4k7; R0402
R96, R97, R98, R99, R102, R103: 220; R0402
R100: DNP; R0402
R101: 1k; R0402
R173: 75; R0402
R174, R175: 100; R0402
T3: B012-617DB-1-63-B331; EASTEVER_BALUN
TP19: TPB1,27; B1,27

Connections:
+3V3: C201.2, IC35.9 (SDI), IC35.10 (DVIO); also elsewhere on the board
+5V/3: L59.2, L60.2, L61.2, L62.2, L63.1, R101.1; also elsewhere on the board
GND: C171.2, C172.2, C175.2, C177.2, C180.2, C181.1, C182.2, C185.2, C186.1, C187.1, C189.2, C190.2, C193.2, C195.2, C198.2, C199.1, C201.1, C204.1, C205.1, IC32.6 (V-), IC33.1 (GND), IC33.2 (GND), IC33.5 (GND), IC33.6 (GND), IC33.8 (GND), IC33.12 (GND), IC33.14 (GND), IC33.17 (GND), IC33.19 (GND), IC33.23 (GND), IC33.25 (GND), IC34.2 (GND), IC35.5 (GND), IC36.9 (GND), L52.2, L53.2, R174.2, R175.2, T3.4 (OUT+); also elsewhere on the board
unnamed: C170.2, T3.6 (OUT-)
unnamed: C178.2, IC33.15 (IN+)
unnamed: C179.2, IC33.16 (IN-)
unnamed: C176.1, C179.1, T3.3 (IN+)
unnamed: C176.2, C178.1, T3.2 (IN-)
unnamed: C185.1, IC33.4 (LO-)
unnamed: C183.2, IC33.3 (LO+)
unnamed: C191.1, IC33.20 (OUT+), L46.2
unnamed: C192.1, IC33.21 (OUT-), L47.2
unnamed: C186.2, IC33.10 (VSET), R100.1, R101.2
unnamed: C199.2, IC36.1 (LO-)
unnamed: C202.1, IC36.6 (OUT+), R102.2
unnamed: C203.1, IC36.5 (OUT-), R103.2
unnamed: C173.1, C202.2, IC32.8 (+IN), R94.1
unnamed: C174.2, C203.2, IC32.1 (-IN), R95.2
unnamed: C174.1, IC32.4 (+OUT), R95.1, R97.2
unnamed: C173.2, IC32.5 (-OUT), R94.2, R96.2
unnamed: C191.2, C194.1, L48.1
unnamed: C192.2, C194.2, L49.1
unnamed: C196.2, L49.2, L51.1
unnamed: C196.1, L48.2, L50.1
unnamed: C197.1, IC36.4 (IN-), L50.2, L52.1
unnamed: C197.2, IC36.3 (IN+), L51.2, L53.1
unnamed: C200.2, IC36.8 (LO+)
unnamed: C187.2, C188.1, IC35.3 (AIN+), R98.1
unnamed: C188.2, C189.1, IC35.4 (AIN-), R99.1
unnamed: C198.1, IC34.5 (VOUT), IC35.2 (AVDD), TP19.TP
unnamed: IC33.11 (DETO), R100.2
unnamed: C270.2, R173.2, R175.1
unnamed: C183.1, R173.1, R174.1
unnamed: C171.1, C172.1, C175.1, C177.1, C180.1, IC33.7 (VPLO), IC33.13 (VPDT), IC33.18 (VPRF), IC33.24 (VPLO), L59.1
unnamed: C190.1, C193.1, L46.1, L47.1, L60.1
unnamed: C204.2, C205.2, IC36.7 (VCC), L61.1, R102.1, R103.1
unnamed: C181.2, IC32.3 (V+), L62.1
unnamed: C195.1, IC34.1 (VIN), IC34.3 (EN), IC35.1 (VREF), L63.2
OUT+2: C184.1, R96.1, R98.2
OUT-2: C184.2, R97.1, R99.2
OUT_CM2: C182.1, IC32.2 (VOCM)
REFLO1: C270.1; also elsewhere on the board
REFLO2: C200.1; also elsewhere on the board
REFMIX1_EN: IC33.9 (ENBL); also elsewhere on the board
REFMIX2_EN: IC32.7 (SHDN), IC36.2 (EN); also elsewhere on the board
REFSRC: C170.1; also elsewhere on the board
REF_CONVSTART: IC35.6 (CONVST); also elsewhere on the board
REF_SCLK: IC35.8 (SCLK); also elsewhere on the board
REF_SDO: IC35.7 (SDO); also elsewhere on the board

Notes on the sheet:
Reference Signal

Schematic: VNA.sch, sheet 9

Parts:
C206, C207, C208, C209, C210, C211, C212, C213, C214, C215, C216, C217, C218, C219, C220, C221, C222: 100n; C0402
C231, C232, C233, C234: 100p; C0402
IC37: STM32G431CB; QFN50P700X700X60-49T560N
J4: TYPE-C16P(073); TYPE-C16P
JP1: DNP; 1X10/90
LED1: Red; CHIPLED_0603
R104, R105, R106, R107, R108, R109, R110: 0; R0402
R111, R112, R113, R114, R115: DNP; R0402
R116, R117, R121, R122, R127, R128, R129, R147, R148: 10k; R0402
R118, R119, R123, R124, R126: 20; R0402
R120: 330; R0402
U1: W25Q16BVSN; SO08
U2: 6SLX9TQG144; TQ144

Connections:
+3V3: C206.1, C207.1, C208.1, C209.1, C210.1, C212.1, C214.1, C216.1, C218.1, C220.1, C221.1, C222.1, IC37.1 (VBAT), IC37.20 (VREF+), IC37.21 (VDDA), IC37.23 (VDD), IC37.35 (VDD), IC37.48 (VDD), JP1.5, LED1.A, R108.1, R116.2, R117.2, R121.2, R127.2, R128.2, R129.2, U1.3 (!WP!), U1.7 (!HOLD!), U1.8 (VCC), U2.P20 (VCCAUX), U2.P36 (VCCAUX), U2.P42 (VCCO_2), U2.P53 (VCCAUX), U2.P63 (VCCO_2), U2.P69 (IO_L1N_M0_CMPMISO_2), U2.P90 (VCCAUX), U2.P129 (VCCAUX); also elsewhere on the board
EN_6V: IC37.25 (PB12); also elsewhere on the board
FPGA_CCLK: R109.2, R111.2, U2.P70 (IO_L1P_CCLK_2)
FPGA_CLK: R126.1; also elsewhere on the board
FPGA_CSO_B: R114.2, U2.P38 (IO_L65N_CSO_B_2)
FPGA_DIN: R110.2, R113.2, U2.P65 (IO_L3P_D0_DIN_MISO_MISO1_2)
FPGA_DONE: IC37.47 (PB9), R129.1, U2.P71 (DONE_2)
FPGA_INIT_B: IC37.6 (PF1-OSC_OUT), R128.1, U2.P39 (IO_L65P_INIT_B_2)
FPGA_M1: R108.2, R115.1, U2.P60 (IO_L13P_M1_2)
FPGA_MOSI: R112.2, U2.P64 (IO_L3N_MOSI_CSI_B_MISO0_2)
FPGA_PROGRAM_B: IC37.19 (PB2), R127.1, U2.P37 (PROGRAM_B_2)
FPGA_RESET: IC37.45 (PB7), U2.P72 (CMPCS_B_2)
GND: C206.2, C207.2, C208.2, C209.2, C210.2, C211.2, C212.2, C213.2, C214.2, C215.2, C216.2, C217.2, C218.2, C219.2, C220.2, C221.2, C222.2, C231.2, C232.2, C233.2, C234.2, IC37.46 (PB8-BOOT0), IC37.49 (GND), J4.1 (GND), J4.12 (GND), J4.M1 (CASE), J4.M2 (CASE), J4.M3 (CASE), J4.M4 (CASE), JP1.7, R115.2, R122.1, U1.4 (GND), U2.P3 (GND), U2.P13 (GND), U2.P25 (GND), U2.P49 (GND), U2.P54 (GND), U2.P68 (GND), U2.P73 (SUSPEND), U2.P77 (GND), U2.P91 (GND), U2.P96 (GND), U2.P108 (GND), U2.P113 (GND), U2.P130 (GND), U2.P136 (GND); also elsewhere on the board
LO1_CE: U2.P45 (IO_L49N_D4_2); also elsewhere on the board
LO1_CLK: U2.P48 (IO_L48P_D7_2); also elsewhere on the board
LO1_LD: U2.P56 (IO_L30P_GCLK1_D13_2); also elsewhere on the board
LO1_LE: U2.P46 (IO_L49P_D3_2); also elsewhere on the board
LO1_MOSI: U2.P47 (IO_L48N_RDWR_B_VREF_2); also elsewhere on the board
LO1_MUX: U2.P51 (IO_L31P_GCLK31_D14_2); also elsewhere on the board
LO1_RF_EN: U2.P55 (IO_L30N_GCLK0_USERCCLK_2); also elsewhere on the board
MCU_AUX1: IC37.9 (PA1); also elsewhere on the board
MCU_AUX2: IC37.10 (PA2); also elsewhere on the board
MCU_AUX3: IC37.11 (PA3); also elsewhere on the board
MCU_FLASH_CS: IC37.17 (PB0), R107.1
MCU_FPGA_CCLK: IC37.26 (PB13), R109.1
MCU_FPGA_DIN: IC37.28 (PB15), R110.1
MCU_FPGA_NSS: IC37.12 (PA4), U2.P67 (IO_L2P_CMPCLK_2)
MCU_FPGA_UNUSED1: IC37.43 (PB5); also elsewhere on the board
MCU_FPGA_UNUSED2: IC37.41 (PB3); also elsewhere on the board
MCU_FPGA_UNUSED3: IC37.40 (PC11); also elsewhere on the board
MCU_INTR: IC37.18 (PB1), U2.P59 (IO_L13N_D10_2)
MCU_MISO: IC37.14 (PA6), R106.1, U2.P62 (IO_L12P_D1_MISO2_2)
MCU_MOSI: IC37.15 (PA7), R105.1, U2.P61 (IO_L12N_D2_MISO3_2)
MCU_SCK: IC37.13 (PA5), R104.1, U2.P66 (IO_L2N_CMPMOSI_2)
unnamed: C232.1, R122.2, R147.1, U2.P57 (IO_L14N_D12_2)
unnamed: J4.6 (D+1), J4.8 (D+2), R119.2
unnamed: IC37.33 (PA11), R118.2
unnamed: IC37.34 (PA12), R119.1
unnamed: J4.5 (D-2), J4.7 (D-1), R118.1
unnamed: LED1.C, R120.1
unnamed: IC37.38 (PA15), R120.2
unnamed: R104.2, R111.1, U1.6 (CLK)
unnamed: R126.2, U2.P50 (IO_L31N_GCLK30_D15_2)
unnamed: R124.2, U2.P41 (IO_L64P_D8_2)
unnamed: R123.2, U2.P43 (IO_L62N_D6_2)
unnamed: IC37.31 (PA9), IC37.44 (PB6), J4.4 (CC1)
unnamed: IC37.32 (PA10), IC37.42 (PB4), J4.10 (CC2)
unnamed: R105.2, R112.1, U1.5 (DI)
unnamed: R106.2, R113.1, U1.2 (DO)
unnamed: R107.2, R114.1, U1.1 (!CS!)
unnamed: C234.1, R121.1, R148.2, U2.P58 (IO_L14P_D11_2)
NRST: IC37.7 (PG10-NRST), JP1.9
PORT2MIX1_EN: C233.1, R148.1; also elsewhere on the board
PORT2MIX2_EN: C231.1, R147.2; also elsewhere on the board
PORT2SWITCH: U2.P40 (IO_L64N_D9_2); also elsewhere on the board
PORT2_CONVSTART: U2.P44 (IO_L62P_D5_2); also elsewhere on the board
PORT2_SCLK: R124.1; also elsewhere on the board
PORT2_SDO: R123.1; also elsewhere on the board
SCL: IC37.16 (PC4), R116.1; also elsewhere on the board
SDA: IC37.30 (PA8), R117.1; also elsewhere on the board
SWCLK: IC37.37 (PA14), JP1.6
SWDIO: IC37.36 (PA13), JP1.8
TCK: JP1.1, U2.P109 (TCK)
TDI: JP1.3, U2.P110 (TDI)
TDO: JP1.2, U2.P106 (TDO)
TMS: JP1.4, U2.P107 (TMS)
UART_TX: IC37.39 (PC10), JP1.10
USB_POWER: J4.2 (VBUS), J4.11 (VBUS); also elsewhere on the board
VCCINT: C211.1, C213.1, C215.1, C217.1, C219.1, U2.P19 (VCCINT), U2.P28 (VCCINT), U2.P52 (VCCINT), U2.P89 (VCCINT), U2.P128 (VCCINT); also elsewhere on the board

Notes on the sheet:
FPGA + MCU Connections
Place resistors for FPGA master configuration
Place resistors for FPGA slave configuration

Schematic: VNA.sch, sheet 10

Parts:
C223, C224, C225, C226, C227, C228, C229, C230: 100p; C0402
JP2: DNP; 2X10
LED2, LED6, LED7, LED8, LED9, LED10: Green; CHIPLED_0603
LED3, LED4, LED5: Red; CHIPLED_0603
R130, R131, R132, R133, R143, R144, R145, R146: 10k; R0402
R134, R135, R136, R137, R138, R139, R140, R141, R142: 330; R0402
U2: 6SLX9TQG144; TQ144

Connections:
+3V3: JP2.1, LED2.A, LED3.A, LED4.A, LED5.A, LED6.A, LED7.A, LED8.A, LED9.A, LED10.A, R130.2, R132.2, U2.P4 (VCCO_3), U2.P18 (VCCO_3), U2.P31 (VCCO_3), U2.P76 (VCCO_1), U2.P86 (VCCO_1), U2.P103 (VCCO_1), U2.P122 (VCCO_0), U2.P125 (VCCO_0), U2.P135 (VCCO_0); also elsewhere on the board
AMP_PWDN: U2.P8 (IO_L51P_3); also elsewhere on the board
ATT_D0: U2.P16 (IO_L43N_GCLK22_IRDY2_3); also elsewhere on the board
ATT_D1: U2.P15 (IO_L44P_GCLK21_3); also elsewhere on the board
ATT_D2: U2.P14 (IO_L44N_GCLK20_3); also elsewhere on the board
ATT_D3: U2.P12 (IO_L49P_3); also elsewhere on the board
ATT_D4: U2.P11 (IO_L49N_3); also elsewhere on the board
ATT_D5: U2.P10 (IO_L50P_3); also elsewhere on the board
ATT_D6: U2.P9 (IO_L50N_3); also elsewhere on the board
FILT_IN_C1: U2.P26 (IO_L37N_3); also elsewhere on the board
FILT_IN_C2: U2.P24 (IO_L41P_GCLK27_3); also elsewhere on the board
FILT_OUT_C1: U2.P22 (IO_L42P_GCLK25_TRDY2_3); also elsewhere on the board
FILT_OUT_C2: U2.P23 (IO_L41N_GCLK26_3); also elsewhere on the board
GND: C223.2, C224.2, C225.2, C226.2, C227.2, C228.2, C229.2, C230.2, JP2.20, R131.1, R133.1, R134.2; also elsewhere on the board
HIGHBAND_SELECT: U2.P21 (IO_L42N_GCLK24_3); also elsewhere on the board
LOWBAND_SELECT: U2.P17 (IO_L43P_GCLK23_3); also elsewhere on the board
MCU_AUX1: U2.P78 (IO_L47N_1); also elsewhere on the board
MCU_AUX2: U2.P74 (IO_L74N_DOUT_BUSY_1); also elsewhere on the board
MCU_AUX3: U2.P75 (IO_L74P_AWAKE_1); also elsewhere on the board
MCU_FPGA_UNUSED1: U2.P79 (IO_L47P_1); also elsewhere on the board
MCU_FPGA_UNUSED2: U2.P80 (IO_L46N_1); also elsewhere on the board
MCU_FPGA_UNUSED3: U2.P81 (IO_L46P_1); also elsewhere on the board
unnamed: C225.1, R132.1, R144.1, U2.P144 (IO_L1P_HSWAPEN_0)
unnamed: C227.1, R131.2, R145.2, U2.P140 (IO_L3P_0)
unnamed: C229.1, R130.1, R146.1, U2.P141 (IO_L2N_0)
unnamed: R135.2, U2.P92 (IO_L41N_GCLK8_1)
unnamed: R136.2, U2.P93 (IO_L41P_GCLK9_IRDY1_1)
unnamed: JP2.2, U2.P134 (IO_L34P_GCLK19_0)
unnamed: JP2.4, U2.P133 (IO_L34N_GCLK18_0)
unnamed: JP2.3, U2.P132 (IO_L35P_GCLK17_0)
unnamed: LED10.C, R142.1
unnamed: LED9.C, R141.1
unnamed: LED8.C, R140.1
unnamed: LED7.C, R139.1
unnamed: LED6.C, R138.1
unnamed: LED5.C, R137.1
unnamed: LED4.C, R136.1
unnamed: LED3.C, R135.1
unnamed: LED2.C, R134.1
unnamed: R142.2, U2.P82 (IO_L45N_1)
unnamed: R141.2, U2.P83 (IO_L45P_1)
unnamed: R140.2, U2.P84 (IO_L43N_GCLK4_1)
unnamed: R139.2, U2.P85 (IO_L43P_GCLK5_1)
unnamed: R138.2, U2.P87 (IO_L42N_GCLK6_TRDY1_1)
unnamed: R137.2, U2.P88 (IO_L42P_GCLK7_1)
unnamed: JP2.6, U2.P131 (IO_L35N_GCLK16_0)
unnamed: JP2.5, U2.P127 (IO_L36P_GCLK15_0)
unnamed: JP2.8, U2.P126 (IO_L36N_GCLK14_0)
unnamed: JP2.7, U2.P124 (IO_L37P_GCLK13_0)
unnamed: JP2.10, U2.P123 (IO_L37N_GCLK12_0)
unnamed: JP2.9, U2.P121 (IO_L62P_0)
unnamed: JP2.12, U2.P120 (IO_L62N_VREF_0)
unnamed: JP2.11, U2.P119 (IO_L63P_SCP7_0)
unnamed: JP2.14, U2.P118 (IO_L63N_SCP6_0)
unnamed: JP2.13, U2.P117 (IO_L64P_SCP5_0)
unnamed: JP2.16, U2.P116 (IO_L64N_SCP4_0)
unnamed: JP2.15, U2.P115 (IO_L65P_SCP3_0)
unnamed: JP2.18, U2.P114 (IO_L65N_SCP2_0)
unnamed: JP2.17, U2.P112 (IO_L66P_SCP1_0)
unnamed: JP2.19, U2.P111 (IO_L66N_SCP0_0)
unnamed: C223.1, R133.2, R143.2, U2.P143 (IO_L1N_VREF_0)
PORT1MIX1_EN: C230.1, R146.2; also elsewhere on the board
PORT1MIX2_EN: C228.1, R145.1; also elsewhere on the board
PORT1SWITCH: U2.P142 (IO_L2P_0); also elsewhere on the board
PORT1_CONVSTART: U2.P139 (IO_L3N_0); also elsewhere on the board
PORT1_SCLK: U2.P137 (IO_L4N_0); also elsewhere on the board
PORT1_SDO: U2.P138 (IO_L4P_0); also elsewhere on the board
PORTSWITCH1: U2.P6 (IO_L52P_3); also elsewhere on the board
PORTSWITCH2: U2.P7 (IO_L51N_3); also elsewhere on the board
REFMIX1_EN: C226.1, R144.2; also elsewhere on the board
REFMIX2_EN: C224.1, R143.1; also elsewhere on the board
REF_CONVSTART: U2.P5 (IO_L52N_3); also elsewhere on the board
REF_SCLK: U2.P1 (IO_L83N_VREF_3); also elsewhere on the board
REF_SDO: U2.P2 (IO_L83P_3); also elsewhere on the board
SOURCE_CE: U2.P27 (IO_L37P_3); also elsewhere on the board
SOURCE_CLK: U2.P32 (IO_L2N_3); also elsewhere on the board
SOURCE_LD: U2.P35 (IO_L1P_3); also elsewhere on the board
SOURCE_LE: U2.P29 (IO_L36N_3); also elsewhere on the board
SOURCE_MOSI: U2.P30 (IO_L36P_3); also elsewhere on the board
SOURCE_MUX: U2.P33 (IO_L2P_3); also elsewhere on the board
SOURCE_RF_EN: U2.P34 (IO_L1N_VREF_3); also elsewhere on the board

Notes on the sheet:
FPGA Connections

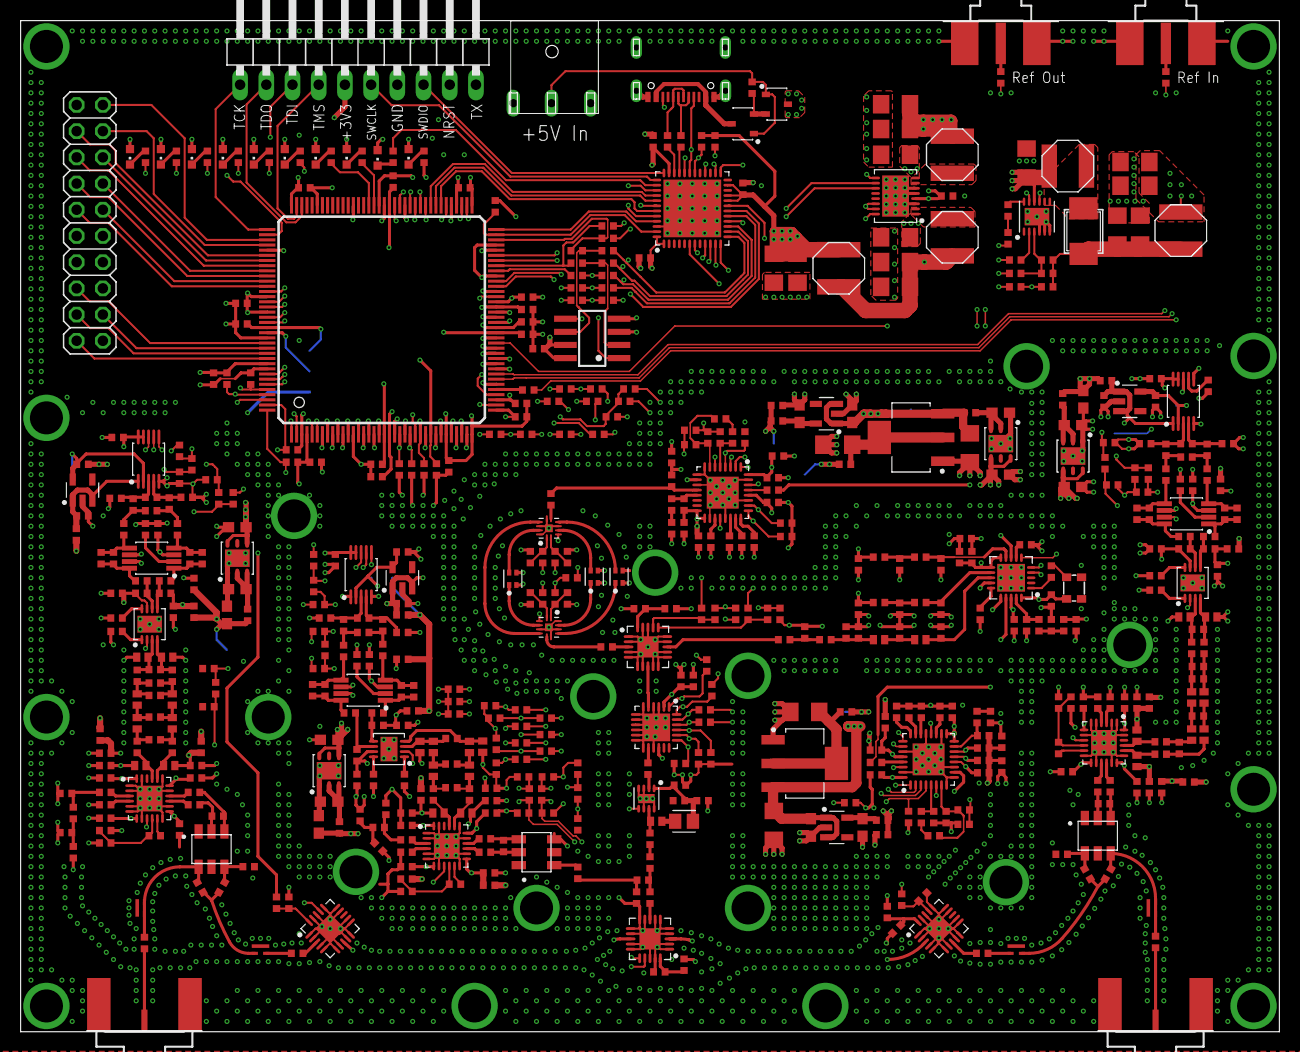
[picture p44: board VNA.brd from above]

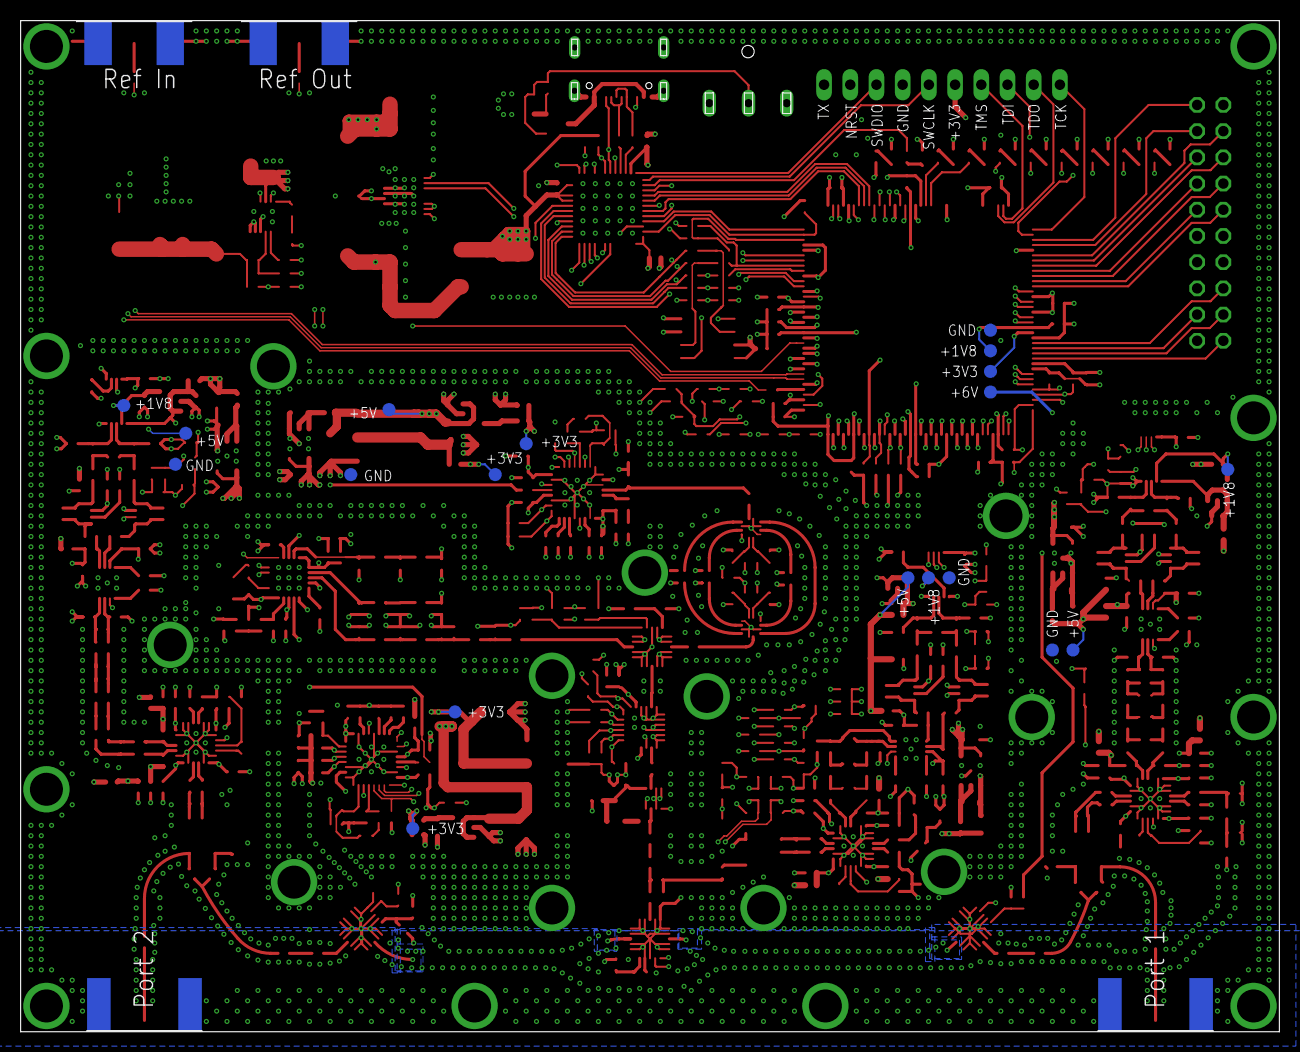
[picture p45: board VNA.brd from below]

Board: 6 copper layers, 122.0 x 98.0 mm, 590 parts (19 on the bottom side), 402 nets.

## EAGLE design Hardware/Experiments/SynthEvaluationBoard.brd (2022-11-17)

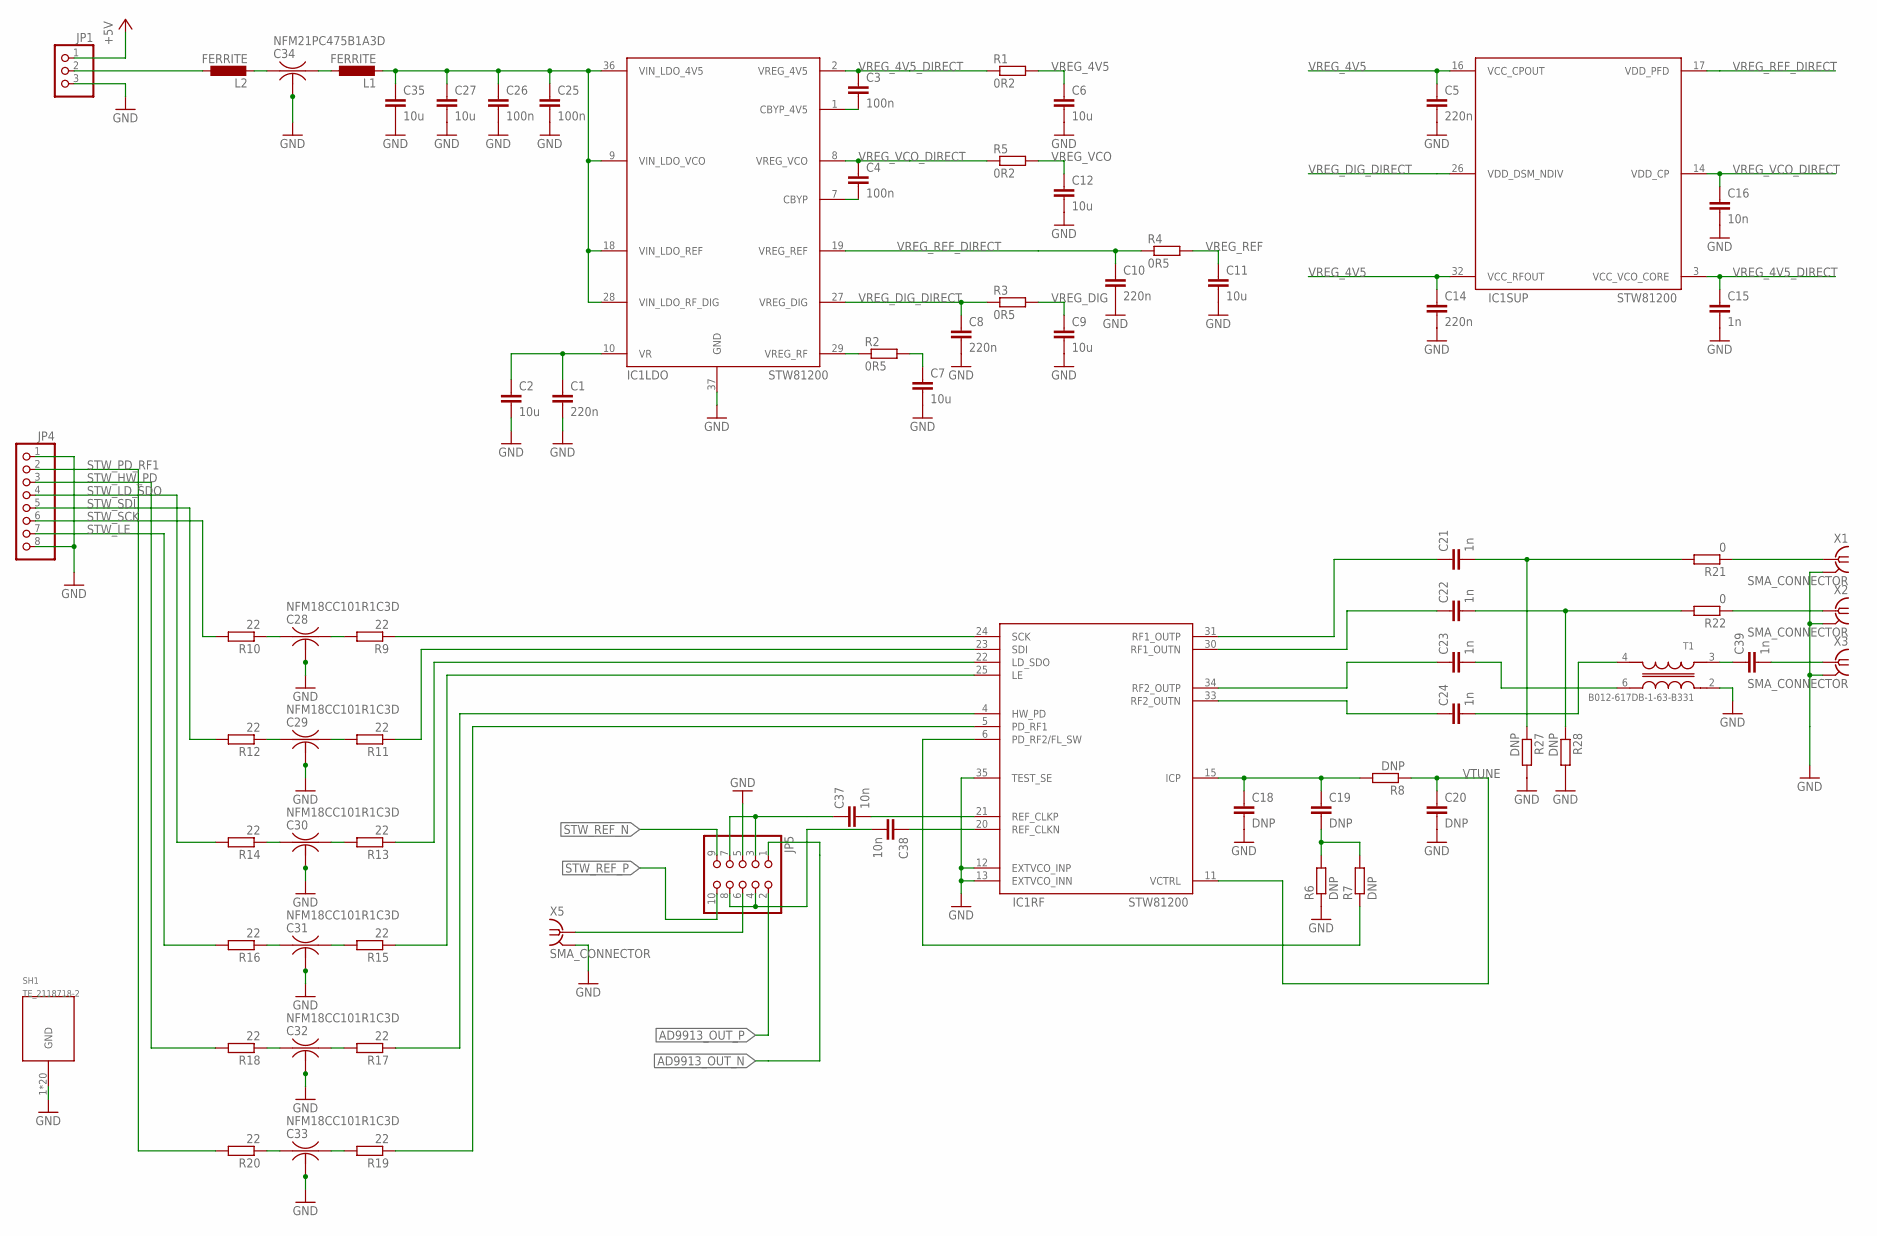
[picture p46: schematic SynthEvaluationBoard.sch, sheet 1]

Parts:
C1, C5, C8, C10, C14: 220n; C0402
C2, C6, C7, C9, C11, C12, C27, C35: 10u; C0603
C3, C4, C25, C26: 100n; C0402
C15, C21, C22, C23, C24, C39: 1n; C0402
C16, C37, C38: 10n; C0402
C18, C19, C20: DNP; C0402
C28, C29, C30, C31, C32, C33: NFM18CC101R1C3D; NFM18PC
C34: NFM21PC475B1A3D; NFM21PC
IC1: STW81200; QFN50P600X600X100-37T410N
JP1: PINHD-1X3; 1X03
JP4: PINHD-1X8; 1X08
JP5: PINHD-2X5; 2X05
L1, L2: FERRITE; R0402
R1, R5: 0R2; R0402
R2, R3, R4: 0R5; R0402
R6, R7, R8, R27, R28: DNP; R0402
R9, R10, R11, R12, R13, R14, R15, R16, R17, R18, R19, R20: 22; R0402
R21, R22: 0; R0402
SH1: TE_2118718-2
T1: B012-617DB-1-63-B331; EASTEVER_BALUN
X1, X2, X3, X5: SMA_CONNECTOR; J502-ND-142-0711-821/826

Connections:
+5V: JP1.1; also elsewhere on the board
AD9913_OUT_N: JP5.1; also elsewhere on the board
AD9913_OUT_P: JP5.2; also elsewhere on the board
GND: C1.2, C2.2, C5.2, C6.2, C7.2, C8.2, C9.2, C10.2, C11.2, C12.2, C14.2, C15.2, C16.2, C18.2, C20.2, C25.2, C26.2, C27.2, C28.2, C28.4 (2), C29.2, C29.4 (2), C30.2, C30.4 (2), C31.2, C31.4 (2), C32.2, C32.4 (2), C33.2, C33.4 (2), C34.2, C34.4 (2), C35.2, IC1.12 (EXTVCO_INP), IC1.13 (EXTVCO_INN), IC1.35 (TEST_SE), IC1.37 (GND), JP1.3, JP4.1, JP4.8, JP5.5, R6.1, R27.2, R28.2, SH1.1, SH1.2, SH1.3, SH1.4, SH1.5, SH1.6, SH1.7, SH1.8, SH1.9, SH1.10, SH1.11, SH1.12, SH1.13, SH1.14, SH1.15, SH1.16, SH1.17, SH1.18, SH1.19, SH1.20, T1.2 (IN-), X1.G@1 (2), X1.G@2 (2), X1.G@3 (2), X1.G@4 (2), X2.G@1 (2), X2.G@2 (2), X2.G@3 (2), X2.G@4 (2), X3.G@1 (2), X3.G@2 (2), X3.G@3 (2), X3.G@4 (2), X5.G@1 (2), X5.G@2 (2), X5.G@3 (2), X5.G@4 (2); also elsewhere on the board
unnamed: C1.1, C2.1, IC1.10 (VR)
unnamed: IC1.6 (PD_RF2/FL_SW), R7.1
unnamed: C4.2, IC1.7 (CBYP)
unnamed: C3.2, IC1.1 (CBYP_4V5)
unnamed: C19.2, R6.2, R7.2
unnamed: C18.1, C19.1, IC1.15 (ICP), R8.2
unnamed: C25.1, C26.1, C27.1, C35.1, IC1.9 (VIN_LDO_VCO), IC1.18 (VIN_LDO_REF), IC1.28 (VIN_LDO_RF_DIG), IC1.36 (VIN_LDO_4V5), L1.2
unnamed: IC1.29 (VREG_RF), R2.1
unnamed: C7.1, R2.2
unnamed: C23.1, IC1.34 (RF2_OUTP)
unnamed: C24.1, IC1.33 (RF2_OUTN)
unnamed: C22.1, IC1.30 (RF1_OUTN)
unnamed: C21.1, IC1.31 (RF1_OUTP)
unnamed: C28.1, R10.1
unnamed: C28.3, R9.2
unnamed: C29.1, R12.1
unnamed: C29.3, R11.2
unnamed: C30.1, R14.1
unnamed: C30.3, R13.2
unnamed: C31.1, R16.1
unnamed: C31.3, R15.2
unnamed: C32.1, R18.1
unnamed: C32.3, R17.2
unnamed: C33.1, R20.1
unnamed: C33.3, R19.2
unnamed: IC1.24 (SCK), R9.1
unnamed: IC1.23 (SDI), R11.1
unnamed: IC1.22 (LD_SDO), R13.1
unnamed: IC1.25 (LE), R15.1
unnamed: IC1.4 (HW_PD), R17.1
unnamed: IC1.5 (PD_RF1), R19.1
unnamed: C34.3, L1.1
unnamed: C34.1, L2.2
unnamed: R22.1, X2.1
unnamed: C22.2, R22.2, R28.1
unnamed: C23.2, T1.6 (OUT-)
unnamed: C39.1, T1.3 (IN+)
unnamed: C21.2, R21.2, R27.1
unnamed: R21.1, X1.1
unnamed: C39.2, X3.1
unnamed: JP5.6, X5.1
unnamed: JP1.2, L2.1
unnamed: C24.2, T1.4 (OUT+)
STW81200_CLK_N: C38.1, IC1.20 (REF_CLKN)
STW81200_CLK_P: C37.2, IC1.21 (REF_CLKP)
STW81200_C_N: C38.2, JP5.4, JP5.8
STW81200_C_P: C37.1, JP5.3, JP5.7
STW_HW_PD: JP4.3, R18.2; also elsewhere on the board
STW_LD_SDO: JP4.4, R14.2; also elsewhere on the board
STW_LE: JP4.7, R16.2; also elsewhere on the board
STW_PD_RF1: JP4.2, R20.2; also elsewhere on the board
STW_REF_N: JP5.9; also elsewhere on the board
STW_REF_P: JP5.10; also elsewhere on the board
STW_SCK: JP4.6, R10.2; also elsewhere on the board
STW_SDI: JP4.5, R12.2; also elsewhere on the board
VREG_4V5: C5.1, C6.1, C14.1, IC1.16 (VCC_CPOUT), IC1.32 (VCC_RFOUT), R1.2
VREG_4V5_DIRECT: C3.1, C15.1, IC1.2 (VREG_4V5), IC1.3 (VCC_VCO_CORE), R1.1
VREG_DIG: C9.1, R3.2
VREG_DIG_DIRECT: C8.1, IC1.26 (VDD_DSM_NDIV), IC1.27 (VREG_DIG), R3.1
VREG_REF: C11.1, R4.2
VREG_REF_DIRECT: C10.1, IC1.17 (VDD_PFD), IC1.19 (VREG_REF), R4.1
VREG_VCO: C12.1, R5.2
VREG_VCO_DIRECT: C4.1, C16.1, IC1.8 (VREG_VCO), IC1.14 (VDD_CP), R5.1
VTUNE: C20.1, IC1.11 (VCTRL), R8.1

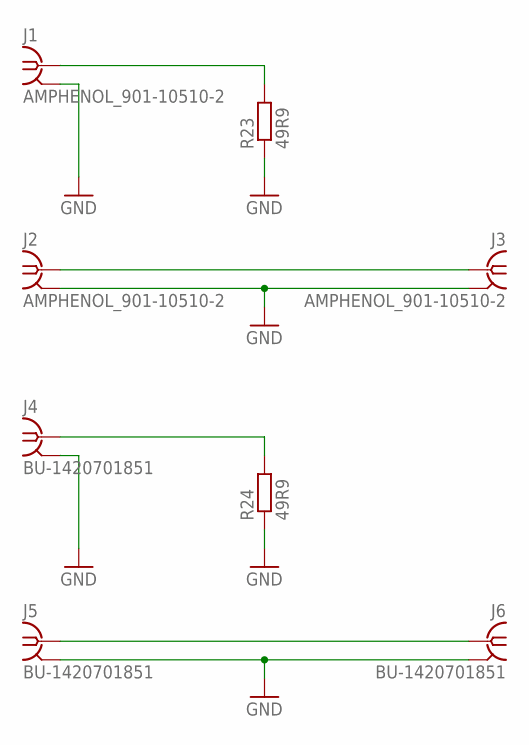
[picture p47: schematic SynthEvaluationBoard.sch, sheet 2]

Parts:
J1, J2, J3: AMPHENOL_901-10510-2
J4, J5, J6: BU-1420701851
R23, R24: 49R9; R0402

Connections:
GND: J1.G1 (2), J1.G2 (2), J1.G3 (2), J1.G4 (2), J2.G1 (2), J2.G2 (2), J2.G3 (2), J2.G4 (2), J3.G1 (2), J3.G2 (2), J3.G3 (2), J3.G4 (2), J4.G@1 (2), J4.G@2 (2), J4.G@3 (2), J4.G@4 (2), J5.G@1 (2), J5.G@2 (2), J5.G@3 (2), J5.G@4 (2), J6.G@1 (2), J6.G@2 (2), J6.G@3 (2), J6.G@4 (2), R23.1, R24.1; also elsewhere on the board
unnamed: J1.S (1), R23.2
unnamed: J2.S (1), J3.S (1)
unnamed: J4.1, R24.2
unnamed: J5.1, J6.1


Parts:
B1: ETC1-1T-2; SM-22
C13, C17, C50, C195, C198: 1u; C0402
C36, C40, C41, C42, C43, C44, C45: 100n; C0402
C46, C49: 12p; C0402
C47, C48: 47p; C0402
IC2: AD9913; QFN50P500X500X80-33T310
IC3, IC34: NCP702-1.8; SOT95P240X110-5
JP3: PINHD-1X8; 1X08
JP6: PINHD-2X3; 2X03
L3, L5, L6, L7: LQW15AWR16J80D; L0402
L4, L8: LQW15CAR27J00D; L0402
L11: FERRITE; R0402
R29: 4k64; R0402
R30, R31: 49R9; R0402
R32, R33: 100; R0402
R34, R35, R36, R37, R38, R39, R40, R41, R42, R43, R44, R45, R46: 1k; R0402
SJ1: SJ
X4, X6: SMA_CONNECTOR; J502-ND-142-0711-821/826

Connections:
+3V3: L11.2; also elsewhere on the board
AD9913_CS: JP3.4, R34.1; also elsewhere on the board
AD9913_IOUT_N: C46.2, IC2.19 (/IOUT), L6.2, R30.2
AD9913_IOUT_P: C46.1, IC2.20 (IOUT), L3.1, R31.2
AD9913_IO_UPDATE: JP3.5, R39.1; also elsewhere on the board
AD9913_MRESET: JP3.7, R37.1; also elsewhere on the board
AD9913_OUT_N: B1.3 (SEC_DOT), C49.2, L7.1; also elsewhere on the board
AD9913_OUT_P: B1.1 (SEC), C49.1, L5.2; also elsewhere on the board
AD9913_PWR_DWN: JP3.6, R38.1; also elsewhere on the board
AD9913_REF_IN_N: C45.1, JP6.3, R32.1
AD9913_REF_IN_P: C44.1, JP6.4, R32.2
AD9913_REF_LVDS_N: JP6.1; also elsewhere on the board
AD9913_REF_LVDS_P: JP6.2; also elsewhere on the board
AD9913_REF_N: C45.2, IC2.14 (/REF_CLK)
AD9913_REF_P: C44.2, IC2.13 (REF_CLK)
AD9913_SCLK: JP3.2, R35.1; also elsewhere on the board
AD9913_SDIO: JP3.3, R36.1, R46.1; also elsewhere on the board
GND: B1.4 (PRI_DOT), C13.2, C17.2, C40.2, C41.2, C42.2, C43.2, C195.2, C198.2, IC2.1 (PS2/ADR5/D5), IC2.2 (PS1/ADR4/D4), IC2.3 (PS0/ADR3/D3), IC2.5 (DGND), IC2.6 (ADR2/D2), IC2.7 (ADR1/D1), IC2.8 (ADR0/D0), IC2.10 (#SER/PAR), IC2.11 (AGND), IC2.15 (AGND), IC2.18 (AGND), IC2.21 (AGND), IC2.23 (AGND), IC2.31 (ADR7/D7), IC2.32 (ADR6/D6), IC2.33 (EP), IC3.2 (GND), IC34.2 (GND), JP3.1, JP3.8, JP6.5, R29.1, R30.1, R31.1, R33.1, R40.1, R41.1, R42.1, R43.1, R44.1, R45.1, SJ1.1, X4.G@1 (2), X4.G@2 (2), X4.G@3 (2), X4.G@4 (2), X6.G@1 (2), X6.G@2 (2), X6.G@3 (2), X6.G@4 (2); also elsewhere on the board
unnamed: C13.1, C195.1, IC3.1 (VIN), IC3.3 (EN), IC34.1 (VIN), IC34.3 (EN), L11.1, R46.2
unnamed: C17.1, C40.1, IC2.4 (DVDD), IC3.5 (VOUT)
unnamed: IC2.24 (RSET), R29.2
unnamed: C36.2, JP6.6, R33.2
unnamed: IC2.28 (/CS), R34.2, R40.2
unnamed: IC2.30 (SCLK), R35.2, R41.2
unnamed: IC2.29 (SDIO), R36.2, R42.2
unnamed: IC2.25 (MASTER_RESET), R37.2, R43.2
unnamed: IC2.26 (PWR_DWN_CTL), R38.2, R44.2
unnamed: IC2.27 (IO_UPDATE), R39.2, R45.2
unnamed: C47.1, L3.2, L4.1
unnamed: C47.2, L6.1, L8.2
unnamed: C48.2, L7.2, L8.1
unnamed: C48.1, L4.2, L5.1
unnamed: B1.2 (SEC_CT), SJ1.2
unnamed: C50.2, X6.1
unnamed: C36.1, X4.1
unnamed: B1.5 (PRI), C50.1
unnamed: C41.1, C42.1, C43.1, C198.1, IC2.12 (AVDD), IC2.16 (AVDD), IC2.17 (AVDD), IC2.22 (AVDD), IC34.5 (VOUT)

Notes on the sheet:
Serial mode selected
All I/O 1V8 only


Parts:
C51, C52, C53, C54, C55, C56, C57, C58, C61: 100n; C0402
C59, C60: 4p; C0402
C62, C63: 1u; C0402
IC4: SI5332A-GM1; QFN50P500X500X100-33T345N
JP2, JP7, JP8, JP11: PINHD-1X3; 1X03
L9, L10: FERRITE; R0402
Q1: FA-128 26MHz; FA-128
R25: 49R9; R0402
X7, X8, X9: SMA_CONNECTOR; J502-ND-142-0711-821/826

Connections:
+3V3: C61.1, C63.1, IC4.1 (VDD_DIG), IC4.4 (VDD_XTAL), L9.1, L10.2; also elsewhere on the board
AD9913_REF_LVDS_N: IC4.21 (OUT3B); also elsewhere on the board
AD9913_REF_LVDS_P: IC4.22 (OUT3); also elsewhere on the board
GND: C51.2, C52.2, C53.2, C54.2, C55.2, C56.2, C57.2, C59.2, C60.2, C61.2, C62.2, C63.2, IC4.33 (GND), JP2.2, JP7.2, JP8.2, JP11.3, Q1.2, Q1.4, R25.1, X7.G@1 (2), X7.G@2 (2), X7.G@3 (2), X7.G@4 (2), X8.G@1 (2), X8.G@2 (2), X8.G@3 (2), X8.G@4 (2), X9.G@1 (2), X9.G@2 (2), X9.G@3 (2), X9.G@4 (2); also elsewhere on the board
unnamed: C57.1, IC4.3 (CLKIN_2B)
unnamed: C58.2, IC4.2 (CLKIN_2), R25.2
unnamed: C58.1, X7.1
unnamed: C60.1, IC4.6 (XB), Q1.3
unnamed: C59.1, IC4.5 (XA/CLKIN1), Q1.1
unnamed: C62.1, IC4.7 (VDDA), L9.2
OUT0_N: IC4.11 (OUT0B), JP2.3
OUT0_P: IC4.12 (OUT0), JP2.1
OUT1_N: IC4.14 (OUT1B), JP8.3
OUT1_P: IC4.15 (OUT1), JP8.1
OUT4_N: IC4.26 (OUT4B), JP7.3
OUT4_P: IC4.27 (OUT4), JP7.1
OUT5_N: IC4.30 (OUT5B), X9.1
OUT5_P: IC4.31 (OUT5), X8.1
SCL: IC4.9 (SCLK), JP11.2; also elsewhere on the board
SDA: IC4.10 (SDA), JP11.1; also elsewhere on the board
SI5332_IN1: IC4.8 (INPUT1); also elsewhere on the board
SI5332_IN2: IC4.17 (INPUT2); also elsewhere on the board
SI5332_IN3: IC4.24 (INPUT3); also elsewhere on the board
SI5332_IN4: IC4.28 (INPUT4); also elsewhere on the board
SI5332_IN5: IC4.29 (INPUT5); also elsewhere on the board
SI5332_VDDO: C51.1, C52.1, C53.1, C54.1, C55.1, C56.1, IC4.13 (VDDO0), IC4.16 (VDDO1), IC4.20 (VDDO2), IC4.23 (VDDO3), IC4.25 (VDDO4), IC4.32 (VDDO5), L10.1
STW_REF_N: IC4.18 (OUT2B); also elsewhere on the board
STW_REF_P: IC4.19 (OUT2); also elsewhere on the board


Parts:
C64, C65, C66, C67, C68: 100n; C0402
C78, C82: 10u; C1206
IC5: STM32L462CE; QFN50P700X700X60-49T560N
IC19: AP2114H; SOT230P700X180-4
JP9: PINHD-1X5; 1X05
JP10, JP12: PINHD-1X3; 1X03
LED1, LED2, LED3, LED4, LED5: Green; LED_SML0603
R26: 10k; R0402
R47, R48: 4k7; R0402
R49, R50: 22; R0402
R51: 1k5; R0402
R52: 470; R0402
R53, R54, R55, R56: 220; R0402
X10: MINI-USB-SCHIELD-32005-301; 32005-301

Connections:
+3V3: C64.1, C65.1, C66.1, C67.1, C82.1, IC5.1 (VBAT), IC5.9 (VDDA/VREF+), IC5.24 (VDD), IC5.36 (VDDUSB), IC5.48 (VDD), IC19.2 (VOUT), IC19.4 (VOUT), JP9.1, R26.2, R47.2, R48.2, R51.1; also elsewhere on the board
+5V: C78.1, IC19.3 (VIN), JP12.2, R52.2; also elsewhere on the board
AD9913_CS: IC5.25 (PB12); also elsewhere on the board
AD9913_IO_UPDATE: IC5.22 (PB11); also elsewhere on the board
AD9913_MRESET: IC5.20 (PB2); also elsewhere on the board
AD9913_PWR_DWN: IC5.21 (PB10); also elsewhere on the board
AD9913_SCLK: IC5.26 (PB13); also elsewhere on the board
AD9913_SDIO: IC5.27 (PB14), IC5.28 (PB15); also elsewhere on the board
GND: C64.2, C65.2, C66.2, C67.2, C68.2, C78.2, C82.2, IC5.8 (VSSA/VREF-), IC5.23 (VSS), IC5.35 (VSS), IC5.44 (PH3-BOOT0), IC5.47 (VSS), IC5.49 (EP), IC19.1 (GND), JP9.3, JP10.2, JP12.3, LED1.C, LED2.C, LED3.C, LED4.C, LED5.C, X10.5, X10.M1 (S1), X10.M2 (S2), X10.M3 (S3), X10.M4 (S4); also elsewhere on the board
unnamed: LED3.A, R52.1
unnamed: JP12.1, X10.1
unnamed: LED1.A, R53.1
unnamed: LED2.A, R54.1
unnamed: LED4.A, R55.1
unnamed: IC5.37 (PA14/SWCLK), JP9.2
unnamed: IC5.34 (PA13/SWDIO), JP9.4
unnamed: C68.1, IC5.7 (NRST), JP9.5, R26.1
unnamed: LED5.A, R56.1
unnamed: IC5.13 (PA3), R53.2
unnamed: IC5.12 (PA2), R54.2
unnamed: IC5.11 (PA1), R55.2
unnamed: IC5.10 (PA0), R56.2
unnamed: R49.2, X10.2
unnamed: R50.1, R51.2, X10.3
unnamed: IC5.32 (PA11), R49.1
unnamed: IC5.33 (PA12), R50.2
RX: IC5.43 (PB7), JP10.3
SCL: IC5.30 (PA9), R47.1; also elsewhere on the board
SDA: IC5.31 (PA10), R48.1; also elsewhere on the board
SI5332_IN1: IC5.38 (PA15); also elsewhere on the board
SI5332_IN2: IC5.29 (PA8); also elsewhere on the board
SI5332_IN3: IC5.39 (PB3); also elsewhere on the board
SI5332_IN4: IC5.40 (PB4); also elsewhere on the board
SI5332_IN5: IC5.41 (PB5); also elsewhere on the board
STW_HW_PD: IC5.18 (PB0); also elsewhere on the board
STW_LD_SDO: IC5.16 (PA6); also elsewhere on the board
STW_LE: IC5.14 (PA4); also elsewhere on the board
STW_PD_RF1: IC5.19 (PB1); also elsewhere on the board
STW_SCK: IC5.15 (PA5); also elsewhere on the board
STW_SDI: IC5.17 (PA7); also elsewhere on the board
TX: IC5.42 (PB6), JP10.1


Board: 4 copper layers, 100.0 x 100.0 mm, 184 parts (0 on the bottom side), 147 nets.

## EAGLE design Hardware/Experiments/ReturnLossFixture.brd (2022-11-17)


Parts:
J1, J2, J3, J4, J5, J6, J7, J8, J9, J10, J11, J12, J13: AMPHENOL_132289
R1, R2, R3, R4, R5, R6, R7, R8: 49R9; R0402
T1: B012-617DB-1-63-B331; EASTEVER_BALUN

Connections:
GND: J1.G@1 (2), J1.G@2 (2), J1.G@3 (2), J1.G@4 (2), J2.G@1 (2), J2.G@2 (2), J2.G@3 (2), J2.G@4 (2), J3.G@1 (2), J3.G@2 (2), J3.G@3 (2), J3.G@4 (2), J4.G@1 (2), J4.G@2 (2), J4.G@3 (2), J4.G@4 (2), J5.G@1 (2), J5.G@2 (2), J5.G@3 (2), J5.G@4 (2), J6.G@1 (2), J6.G@2 (2), J6.G@3 (2), J6.G@4 (2), J7.G@1 (2), J7.G@2 (2), J7.G@3 (2), J7.G@4 (2), J8.G@1 (2), J8.G@2 (2), J8.G@3 (2), J8.G@4 (2), J9.G@1 (2), J9.G@2 (2), J9.G@3 (2), J9.G@4 (2), J10.G@1 (2), J10.G@2 (2), J10.G@3 (2), J10.G@4 (2), J11.G@1 (2), J11.G@2 (2), J11.G@3 (2), J11.G@4 (2), J12.G@1 (2), J12.G@2 (2), J12.G@3 (2), J12.G@4 (2), J13.G@1 (2), J13.G@2 (2), J13.G@3 (2), J13.G@4 (2), R1.1, R2.1, R3.1, R4.1, R5.1, R6.1
unnamed: J1.1, R1.2
unnamed: J2.1, R2.2
unnamed: J3.1, R3.2
unnamed: J4.1, R4.2
unnamed: J5.1, R5.2
unnamed: J6.1, J7.1
unnamed: J10.1, R8.2, T1.6 (OUT-)
unnamed: J8.1, J9.1
unnamed: J12.1, T1.3 (IN+)
unnamed: J11.1, T1.2 (IN-)
unnamed: R6.2, R7.2, T1.4 (OUT+)
unnamed: J13.1, R7.1, R8.1


Board: 4 copper layers, 50.0 x 100.0 mm, 22 parts (0 on the bottom side), 13 nets.

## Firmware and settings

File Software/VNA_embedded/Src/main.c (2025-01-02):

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
/* Includes ------------------------------------------------------------------*/
#include "main.h"
#include "cmsis_os.h"

/* USER CODE BEGIN Includes */
#include "App.h"
/* USER CODE END Includes */

ADC_HandleTypeDef hadc1;

I2C_HandleTypeDef hi2c2;

SPI_HandleTypeDef hspi1;
SPI_HandleTypeDef hspi2;
DMA_HandleTypeDef hdma_spi1_rx;
DMA_HandleTypeDef hdma_spi1_tx;

TIM_HandleTypeDef htim1;
TIM_HandleTypeDef htim2;

UART_HandleTypeDef huart3;

PCD_HandleTypeDef hpcd_USB_FS;

osThreadId defaultTaskHandle;
uint32_t defaultTaskBuffer[ 1024 ];
osStaticThreadDef_t defaultTaskControlBlock;
void SystemClock_Config(void);
static void MX_GPIO_Init(void);
static void MX_DMA_Init(void);
static void MX_I2C2_Init(void);
static void MX_SPI1_Init(void);
static void MX_SPI2_Init(void);
static void MX_UCPD1_Init(void);
static void MX_USART3_UART_Init(void);
static void MX_USB_PCD_Init(void);
static void MX_TIM1_Init(void);
static void MX_TIM2_Init(void);
static void MX_ADC1_Init(void);
void StartDefaultTask(void const * argument);

/**
  * @brief  The application entry point.
  * @retval int
  */
int main(void)
{
  /* MCU Configuration--------------------------------------------------------*/

  /* Reset of all peripherals, Initializes the Flash interface and the Systick. */
  HAL_Init();

  /* Configure the system clock */
  SystemClock_Config();

  /* USER CODE BEGIN SysInit */
  MX_I2C2_Init();
  uint8_t ctrl = 0x09;
  HAL_I2C_Mem_Write(&hi2c2, 0x42, 0x01, I2C_MEMADD_SIZE_8BIT, &ctrl, 1, 100);
  /* USER CODE END SysInit */

  /* Initialize all configured peripherals */
  MX_GPIO_Init();
  MX_DMA_Init();
  MX_I2C2_Init();
  MX_SPI1_Init();
  MX_SPI2_Init();
  MX_UCPD1_Init();
  MX_USART3_UART_Init();
  MX_USB_PCD_Init();
  MX_TIM1_Init();
  MX_TIM2_Init();
  MX_ADC1_Init();
  /* USER CODE BEGIN RTOS_MUTEX */
  /* add mutexes, ... */
  /* USER CODE END RTOS_MUTEX */

  /* USER CODE BEGIN RTOS_SEMAPHORES */
  /* add semaphores, ... */
  /* USER CODE END RTOS_SEMAPHORES */

  /* USER CODE BEGIN RTOS_TIMERS */
  /* start timers, add new ones, ... */
  /* USER CODE END RTOS_TIMERS */

  /* USER CODE BEGIN RTOS_QUEUES */
  /* add queues, ... */
  /* USER CODE END RTOS_QUEUES */

  /* Create the thread(s) */
  /* definition and creation of defaultTask */
  osThreadStaticDef(defaultTask, StartDefaultTask, osPriorityNormal, 0, 1024, defaultTaskBuffer, &defaultTaskControlBlock);
  defaultTaskHandle = osThreadCreate(osThread(defaultTask), NULL);

  /* USER CODE BEGIN RTOS_THREADS */
  /* add threads, ... */
  /* USER CODE END RTOS_THREADS */

  /* Start scheduler */
  osKernelStart();

  /* We should never get here as control is now taken by the scheduler */
  /* Infinite loop */
  /* USER CODE BEGIN WHILE */
  while (1)
  {
    /* USER CODE END WHILE */

    /* USER CODE BEGIN 3 */
  }
  /* USER CODE END 3 */
}

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
/* USER CODE BEGIN Header_StartDefaultTask */
/**
  * @brief  Function implementing the defaultTask thread.
  * @param  argument: Not used
  * @retval None
  */
/* USER CODE END Header_StartDefaultTask */
void StartDefaultTask(void const * argument)
{
  /* USER CODE BEGIN 5 */
  App_Start();
  /* Infinite loop */
  for(;;)
  {
    osDelay(1);
  }
  /* USER CODE END 5 */
}

/**
  * @brief  Period elapsed callback in non blocking mode
  * @note   This function is called  when TIM17 interrupt took place, inside
  * HAL_TIM_IRQHandler(). It makes a direct call to HAL_IncTick() to increment
  * a global variable "uwTick" used as application time base.
  * @param  htim : TIM handle
  * @retval None
  */
void HAL_TIM_PeriodElapsedCallback(TIM_HandleTypeDef *htim)
{
  if (htim->Instance == TIM17) {
    HAL_IncTick();
  }
}

/**
  * @brief  This function is executed in case of error occurrence.
  * @retval None
  */
void Error_Handler(void)
{
  /* USER CODE BEGIN Error_Handler_Debug */
  /* User can add his own implementation to report the HAL error return state */
  __disable_irq();
  while (1)
  {
  }
  /* USER CODE END Error_Handler_Debug */
}

#ifdef  USE_FULL_ASSERT
/**
  * @brief  Reports the name of the source file and the source line number
  *         where the assert_param error has occurred.
  * @param  file: pointer to the source file name
  * @param  line: assert_param error line source number
  * @retval None
  */
void assert_failed(uint8_t *file, uint32_t line)
{
  /* USER CODE BEGIN 6 */
  /* User can add his own implementation to report the file name and line number,
     ex: printf("Wrong parameters value: file %s on line %d\r\n", file, line) */
  /* USER CODE END 6 */
}
#endif /* USE_FULL_ASSERT */

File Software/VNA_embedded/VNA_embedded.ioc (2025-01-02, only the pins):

Mcu.UserName=STM32G431CBUx
PA1.GPIO_Label=FPGA_AUX1
PA1.Signal=GPIO_Output
PA10.Signal=UCPD1_DBCC2
PA11.Signal=USB_DM
PA12.Signal=USB_DP
PA13.Signal=SYS_JTMS-SWDIO
PA14.Signal=SYS_JTCK-SWCLK
PA15.Signal=S_TIM2_CH1
PA2.GPIO_Label=FPGA_AUX3
PA2.Signal=GPIO_Output
PA3.GPIO_Label=FPGA_AUX2
PA3.Signal=GPIO_Output
PA4.GPIO_Label=FPGA_CS
PA4.Signal=GPIO_Output
PA5.Signal=SPI1_SCK
PA6.Signal=SPI1_MISO
PA7.Signal=SPI1_MOSI
PA8.Signal=I2C2_SDA
PA9.Signal=UCPD1_DBCC1
PB0.GPIO_Label=FLASH_CS
PB0.Signal=GPIO_Output
PB1.GPIO_Label=FPGA_INTR
PB1.Signal=GPXTI1
PB11.Signal=USART3_RX
PB12.GPIO_Label=EN_6V
PB12.Signal=GPIO_Output
PB13.Signal=SPI2_SCK
PB15.Signal=SPI2_MOSI
PB2.GPIO_Label=FPGA_PROGRAM_B
PB2.Signal=GPIO_Output
PB3.GPIO_Label=FPGA_TRIGGER_IN
PB3.Signal=GPIO_Output
PB4.Signal=UCPD1_CC2
PB5.GPIO_Label=FPGA_RESET
PB5.Signal=GPIO_Output
PB6.Signal=UCPD1_CC1
PB9.GPIO_Label=FPGA_DONE
PB9.Signal=GPIO_Input
PC10.Signal=USART3_TX
PC11.GPIO_Label=FPGA_TRIGGER_OUT
PC11.Signal=GPIO_Input
PC4.Signal=I2C2_SCL
PF1-OSC_OUT.GPIO_Label=FPGA_INIT_B
PF1-OSC_OUT.Signal=GPIO_Input

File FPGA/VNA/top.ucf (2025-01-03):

CONFIG VCCAUX  = 3.3;
# Global FPGA clock
NET "CLK" PERIOD = 62.5 ns HIGH 50%;

# Constraints for SPI interface to MCU
NET "MCU_SCK" PERIOD = 23.52941176ns HIGH 50%;
NET "MCU_MOSI" OFFSET = IN 2ns VALID 3ns BEFORE "MCU_SCK";
NET "MCU_MISO" OFFSET = OUT 18.529ns VALID 10ns AFTER "MCU_SCK";
NET "MCU_MISO" SLEW = FAST;

# ADC constraints
NET "REF_SCLK" PERIOD = 19.5ns HIGH 50%;
NET "REF_SDO" OFFSET = IN 	9ns VALID 9ns BEFORE "REF_SCLK";
NET "PORT1_SCLK" PERIOD = 19.5ns HIGH 50%;
NET "PORT1_SDO" OFFSET = IN 	9ns VALID 9ns BEFORE "PORT1_SCLK";
NET "PORT2_SCLK" PERIOD = 19.5ns HIGH 50%;
NET "PORT2_SDO" OFFSET = IN 	9ns VALID 9ns BEFORE "PORT2_SCLK";
NET "PORT1_SCLK" SLEW = FAST;
NET "PORT2_SCLK" SLEW = FAST;
NET "REF_SCLK" SLEW = FAST;

NET "ATTENUATION[6]" IOSTANDARD = LVCMOS33;
NET "ATTENUATION[5]" IOSTANDARD = LVCMOS33;
NET "ATTENUATION[4]" IOSTANDARD = LVCMOS33;
NET "ATTENUATION[3]" IOSTANDARD = LVCMOS33;
NET "ATTENUATION[2]" IOSTANDARD = LVCMOS33;
NET "ATTENUATION[1]" IOSTANDARD = LVCMOS33;
NET "ATTENUATION[0]" IOSTANDARD = LVCMOS33;

NET "LEDS[7]" IOSTANDARD = LVCMOS33;
NET "LEDS[6]" IOSTANDARD = LVCMOS33;
NET "LEDS[5]" IOSTANDARD = LVCMOS33;
NET "LEDS[4]" IOSTANDARD = LVCMOS33;
NET "LEDS[3]" IOSTANDARD = LVCMOS33;
NET "LEDS[2]" IOSTANDARD = LVCMOS33;
NET "LEDS[1]" IOSTANDARD = LVCMOS33;
NET "LEDS[0]" IOSTANDARD = LVCMOS33;

NET "AMP_PWDN" IOSTANDARD = LVCMOS33;
NET "CLK" IOSTANDARD = LVCMOS33;
NET "FILT_IN_C2" IOSTANDARD = LVCMOS33;
NET "FILT_IN_C1" IOSTANDARD = LVCMOS33;
NET "FILT_OUT_C2" IOSTANDARD = LVCMOS33;
NET "FILT_OUT_C1" IOSTANDARD = LVCMOS33;
NET "LO1_CE" IOSTANDARD = LVCMOS33;
NET "LO1_LD" IOSTANDARD = LVCMOS33;
NET "LO1_LE" IOSTANDARD = LVCMOS33;
NET "LO1_CLK" IOSTANDARD = LVCMOS33;
NET "LO1_MOSI" IOSTANDARD = LVCMOS33;
NET "LO1_MUX" IOSTANDARD = LVCMOS33;
NET "MCU_AUX1" IOSTANDARD = LVCMOS33;
NET "LO1_RF_EN" IOSTANDARD = LVCMOS33;
NET "SOURCE_RF_EN" IOSTANDARD = LVCMOS33;
NET "SOURCE_MUX" IOSTANDARD = LVCMOS33;
NET "SOURCE_LE" IOSTANDARD = LVCMOS33;
NET "SOURCE_MOSI" IOSTANDARD = LVCMOS33;
NET "SOURCE_LD" IOSTANDARD = LVCMOS33;
NET "SOURCE_CLK" IOSTANDARD = LVCMOS33;
NET "SOURCE_CE" IOSTANDARD = LVCMOS33;
NET "RESET" IOSTANDARD = LVCMOS33;
NET "REF_SDO" IOSTANDARD = LVCMOS33;
NET "REF_SCLK" IOSTANDARD = LVCMOS33;
NET "REF_CONVSTART" IOSTANDARD = LVCMOS33;
NET "PORT2_SDO" IOSTANDARD = LVCMOS33;
NET "PORT2_SCLK" IOSTANDARD = LVCMOS33;
NET "PORT2_CONVSTART" IOSTANDARD = LVCMOS33;
NET "PORT1_SDO" IOSTANDARD = LVCMOS33;
NET "PORT1_SCLK" IOSTANDARD = LVCMOS33;
NET "PORT1_CONVSTART" IOSTANDARD = LVCMOS33;
NET "MCU_SCK" IOSTANDARD = LVCMOS33;
NET "MCU_NSS" IOSTANDARD = LVCMOS33;
NET "MCU_MISO" IOSTANDARD = LVCMOS33;
NET "MCU_MOSI" IOSTANDARD = LVCMOS33;
NET "MCU_INTR" IOSTANDARD = LVCMOS33;
NET "MCU_AUX2" IOSTANDARD = LVCMOS33;
NET "MCU_AUX3" IOSTANDARD = LVCMOS33;
NET "TRIGGER_IN" IOSTANDARD = LVCMOS33;
NET "TRIGGER_OUT" IOSTANDARD = LVCMOS33;

NET "ATTENUATION[6]" LOC = P9;
NET "ATTENUATION[5]" LOC = P10;
NET "ATTENUATION[4]" LOC = P11;
NET "ATTENUATION[3]" LOC = P12;
NET "ATTENUATION[2]" LOC = P14;
NET "ATTENUATION[1]" LOC = P15;
NET "ATTENUATION[0]" LOC = P16;
NET "LEDS[0]" LOC = P87;
NET "LEDS[1]" LOC = P92;
NET "LEDS[2]" LOC = P93;
NET "LEDS[3]" LOC = P88;
NET "LEDS[4]" LOC = P85;
NET "LEDS[5]" LOC = P84;
NET "LEDS[6]" LOC = P83;
NET "LEDS[7]" LOC = P82;
NET "AMP_PWDN" LOC = P8;
NET "BAND_SELECT_HIGH" LOC = P21;
NET "BAND_SELECT_LOW" LOC = P17;
NET "CLK" LOC = P50;
NET "FILT_IN_C1" LOC = P26;
NET "FILT_IN_C2" LOC = P24;
NET "FILT_OUT_C1" LOC = P22;
NET "FILT_OUT_C2" LOC = P23;
NET "LO1_CE" LOC = P45;
NET "LO1_CLK" LOC = P48;
NET "LO1_LD" LOC = P56;
NET "LO1_LE" LOC = P46;
NET "LO1_MOSI" LOC = P47;
NET "LO1_MUX" LOC = P51;
NET "LO1_RF_EN" LOC = P55;
NET "MCU_AUX1" LOC = P78;
NET "MCU_AUX2" LOC = P75;
NET "MCU_AUX3" LOC = P74;
NET "TRIGGER_IN" LOC = P80;
NET "TRIGGER_OUT" LOC = P81;
NET "MCU_INTR" LOC = P59;
NET "MCU_MISO" LOC = P62;
NET "MCU_MOSI" LOC = P61;
NET "MCU_NSS" LOC = P67;
NET "MCU_SCK" LOC = P66;
NET "MCU_SCK" CLOCK_DEDICATED_ROUTE = FALSE;

# PlanAhead Generated physical constraints 

NET "PORT1_CONVSTART" LOC = P139;
NET "PORT1_MIX1_EN" LOC = P141;
NET "PORT1_MIX2_EN" LOC = P140;
NET "PORT1_SCLK" LOC = P137;
NET "PORT1_SDO" LOC = P138;
NET "PORT1_SELECT" LOC = P142;
NET "PORT2_CONVSTART" LOC = P44;
NET "PORT2_MIX1_EN" LOC = P58;
NET "PORT2_MIX2_EN" LOC = P57;
NET "PORT2_SCLK" LOC = P41;
NET "PORT2_SDO" LOC = P43;
NET "PORT2_SELECT" LOC = P40;
NET "PORT_SELECT1" LOC = P6;
NET "PORT_SELECT2" LOC = P7;
NET "REF_CONVSTART" LOC = P5;
NET "REF_MIX1_EN" LOC = P144;
NET "REF_MIX2_EN" LOC = P143;
NET "REF_SCLK" LOC = P1;
NET "REF_SDO" LOC = P2;
NET "RESET" LOC = P79;
NET "SOURCE_CE" LOC = P27;
NET "SOURCE_CLK" LOC = P32;
NET "SOURCE_LD" LOC = P35;
NET "SOURCE_LE" LOC = P29;
NET "SOURCE_MOSI" LOC = P30;
NET "SOURCE_MUX" LOC = P33;
NET "SOURCE_RF_EN" LOC = P34;

# PlanAhead Generated IO constraints 

NET "BAND_SELECT_HIGH" IOSTANDARD = LVCMOS33;
NET "BAND_SELECT_LOW" IOSTANDARD = LVCMOS33;
NET "PORT1_MIX1_EN" IOSTANDARD = LVCMOS33;
NET "PORT1_MIX2_EN" IOSTANDARD = LVCMOS33;
NET "PORT1_SELECT" IOSTANDARD = LVCMOS33;
NET "PORT2_MIX1_EN" IOSTANDARD = LVCMOS33;
NET "PORT2_MIX2_EN" IOSTANDARD = LVCMOS33;
NET "PORT2_SELECT" IOSTANDARD = LVCMOS33;
NET "PORT_SELECT1" IOSTANDARD = LVCMOS33;
NET "PORT_SELECT2" IOSTANDARD = LVCMOS33;
NET "REF_MIX1_EN" IOSTANDARD = LVCMOS33;
NET "REF_MIX2_EN" IOSTANDARD = LVCMOS33;

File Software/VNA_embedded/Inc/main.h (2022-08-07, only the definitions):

#define FPGA_INIT_B_Pin GPIO_PIN_1
#define FPGA_INIT_B_GPIO_Port GPIOF
#define FPGA_AUX1_Pin GPIO_PIN_1
#define FPGA_AUX1_GPIO_Port GPIOA
#define FPGA_AUX3_Pin GPIO_PIN_2
#define FPGA_AUX3_GPIO_Port GPIOA
#define FPGA_AUX2_Pin GPIO_PIN_3
#define FPGA_AUX2_GPIO_Port GPIOA
#define FPGA_CS_Pin GPIO_PIN_4
#define FPGA_CS_GPIO_Port GPIOA
#define FLASH_CS_Pin GPIO_PIN_0
#define FLASH_CS_GPIO_Port GPIOB
#define FPGA_INTR_Pin GPIO_PIN_1
#define FPGA_INTR_GPIO_Port GPIOB
#define FPGA_PROGRAM_B_Pin GPIO_PIN_2
#define FPGA_PROGRAM_B_GPIO_Port GPIOB
#define EN_6V_Pin GPIO_PIN_12
#define EN_6V_GPIO_Port GPIOB
#define FPGA_TRIGGER_OUT_Pin GPIO_PIN_11
#define FPGA_TRIGGER_OUT_GPIO_Port GPIOC
#define FPGA_TRIGGER_IN_Pin GPIO_PIN_3
#define FPGA_TRIGGER_IN_GPIO_Port GPIOB
#define FPGA_RESET_Pin GPIO_PIN_5
#define FPGA_RESET_GPIO_Port GPIOB
#define FPGA_DONE_Pin GPIO_PIN_9
#define FPGA_DONE_GPIO_Port GPIOB

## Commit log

2020-07-25 Schematic + some placement
    [VNA.brd, VNA.sch]
2020-08-01 Routing completed
    [VNA.brd, VNA.sch]
2020-08-02 Routing + BOM
    [BOM.ods, VNA.brd, VNA.sch]
2020-08-02 library update
    [VNA.brd, VNA.sch]
2020-08-03 reworked power supply section
    [BOM.ods, VNA.brd, VNA.sch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]
2020-08-04 RFCase, BOM adjustments, renderings
    [BOM.ods, BottomShield.step, TopShield.step]
2020-08-04 Removed non-required files
    [VNA_bottom.dxf, VNA_top.dxf]
2020-08-05 TCXO instead of crystal
    [BOM.ods, VNA.brd, VNA.sch]
2020-08-05 GND cutouts under RF component pads
    [VNA.brd]
2020-08-07 R27 value fixed
    [BOM.ods, VNA.brd, VNA.sch]
2020-08-24 embedded code copied from jankae/VNA and adjusted for STM32G4
    [New_configuration.cfg]
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2020-08-31 Main thread using FreeRTOS notifications, added missing commands for firmware update
2020-09-01 Search for rebooted device after update
2020-09-06 Trace for port switch moved to fix short with aluminium shield
    [VNA.brd]
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2020-09-14 Bugfixes and improvements for new hardware
    [New_configuration.cfg]
2020-09-15 automatic driver installation on Windows using WCID, changed PID to avoid collision
    [usb.c]
2020-09-15 Bugfixes
    - Firmware update device reattachment
    - Disconnect/connect with multiple devices
    - udev rule extended
    [FPGA.cpp, Firmware.cpp]
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2020-09-17 Improved spectrum analyzer mode
    - Faster sweeps by changing 2.LO only when necessary and using 400kHz I2C frequency
    - Added FPGA settings for selectable ADC samplerate
    - Additional measurement with different ADC samplerate when signal ID is on to remove ADC images
2020-09-20 Bugfix: only enable highband source once per sweep
    [FPGA.cpp]
2020-09-20 Footprint adjustments for THS4521/0402 inductors, fixed mixup of CCLK/DIN
    [VNA.brd, VNA.sch]
2020-09-21 Additional screws
    [VNA.brd]
2020-09-21 DC jack with power priority over USB
    [VNA.brd, VNA.sch]
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2020-09-26 Bugfixes and speed improvements
    [FPGA.cpp, Hardware.cpp, Hardware.hpp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]
2020-09-27 Updated step files
    [BottomShield.step, TopShield.step]
2020-09-27 Updated BOM
    [BOM.ods, VNA.brd, VNA.sch]
2020-09-27 Bugfix: race condition removed when changing settings on fast sweep
    [Hardware.cpp, Hardware.hpp]
2020-09-28 Schematic PDF
    [VNA.brd, VNA.sch]
2020-09-29 Improved USB throughput, stimulus power up to 0dbm, fine tuning of dynamic range
2020-09-30 Additional filters for digital control lines, attenuator for Port1/Ref 1.LO
    [BOM.ods, VNA.brd, VNA.sch]
2020-10-01 0402 pads reduced in size
    [VNA.brd, VNA.sch]
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2020-10-03 Silkscreen adjustments
    [VNA.brd]
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2020-10-24 backup button icons in case of missing theme
2020-10-29 Various small bugfixes
    - Improved device communication (callbacks for transmissions working properly now)
    - Honor averaging when calibrating
    - Ignore delayed points from last sweep during calibration
    - Stop the sweep when disconnecting
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2020-11-09 Bugfix: Use correct Z0 in calibration kit parsing
2020-11-10 More intuitive handling of calibration measurements
    - Allow saving of calibration only if a calibration is active (no more
    calibration files that "don't do anything" when they are opened)
    - Delete old measurements when loading a new calibration file
    - Update calibration when a measurement is updated (no need to disable
    and enable again)
    - Disable calibration when a required measurement is deleted
2020-11-12 Minor GUI improvements
    - allow 'wrong' input for unit edits where only one case makes sense (e.g. 10mHz for 10MHz)
    - fix behavior when changing center of span would exceed the allowed range
    - only change value for level or points when editing is finished (not on every keyboard input)
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2020-11-16 work around WinUSB limitation of only one open device handle
    [VNA_embedded Debug.cfg]
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2020-11-18 Bugfixes automatic source/receiver calibration
2020-11-23 vna.cpp - cosmetic change siunitedit.cpp - keep text onFocus tracewidget.cpp - invalid index or empty list
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2020-11-24 detect missing points + minor USB speedup
    [VNA_embedded.ioc, main.c, usb.c]
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2020-11-27 Prevent crash on Y-axis autoscale when all trace values are identical
2020-11-27 Option to view raw calibration measurements + calkit typos fixed
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2020-12-15 Timeout handling in FPGA communication (better recovery from missing reference)
    [Hardware.cpp, Hardware.hpp]
2020-12-17 XY-Plot setup handling improved
    - Use readable names for axis type/mode in json (old integer encoding still valid when loading old setups)
    - Bugfix: time domain traces not included in context menu when plot is constructed after the trace
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2021-01-31 Bugfixes DC jack/amplifier
    [BOM.ods, VNA.brd, VNA.sch]
2021-02-02 Clearance between case and USB-C connector reduced
    [TopShield.step]
2021-02-11 display error flags in statusbar (overload/unlock/unlevel)
    [Hardware.cpp, Hardware.hpp]
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2021-02-23 Increase thickness for easier manufacturing of blind holes
    [TopShield.step]
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2021-03-22 minor spur/phase noise improvements
    [Hardware.cpp, Hardware.hpp]
2021-03-22 Bugfix: hide de-embedding menu in generator/SA modes
2021-04-10 Set unlevel flag after mode switch to prevent immediate reset
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2021-05-08 Bugfix: use correct PLL frequency when switching between internal/external reference
    [Hardware.cpp]
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2021-06-02 Possible reference output frequency fix?
    [Hardware.cpp, Hardware.hpp]
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2021-06-08 Fix parsing of calibration kit dialog entries
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2021-07-02 Script for measuring ADC noise
2021-07-03 gui: set individual plot as full screen when double clicked
    The following commit features to set specific plot as full screen
    if double clicked event is triggered while mouse is over that
    particular plot.
    This becomes handy if you are interested in a particular traces over
    that plot and want to inspect it in more detail.
2021-07-08 Add missing radius
    [BottomShield.step]
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2021-07-09 Allow different source PLL power per sweep point, add power range to sweep
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2021-07-10 Add setting for graph behavior when trace no longer supported
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2021-07-10 bugfixes power sweep handling
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2021-07-19 fw/hardware: disable debug pins
    When USE_DEBUG_PINS is enabled and debug session is open, their pin
    initialization makes debug probe to lost session. As these pins are
    not used, let's disable it by default.
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2021-10-15 gui: implement status bar based upon device state
    When device has not been connected for the first time,
    status bar doesn't any information.
    This implementation tries to encapsulate changes required on
    several widgets associated with status bar based upon device state
    whether this has been connected or not.
2021-10-16 gui/traces: prevent out of range when marker is added on smith chart
    When a marker is added in enabled trace for smith chart and there no
    samples received yet, an out of range is produced causing that
    application closes. This implementation set closes point when
    iterating over samples preventing mentioned behavior.
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2021-10-19 gui/plotxy: implement background ticks
    Improve trace readability when is displayed on xy plot.
    The user is able to enable this option throughout preferences dialog.
2021-10-20 gui/traces: highlight traces and markers name in xyplot
    When a trace is added to any plot it will appear as a label
    within a rounded colored box. The same applies for any marker
    added highlighting only marker number.
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2021-10-30 Fix corner-case calculation of secondary Y axis background coordinates
2021-11-11 fix plot drawing in case of autoscale and no trace data
2021-11-13 gui/plotxy: fix hidden description in filter markers related
2021-11-13 Prevent crash when attempting to move marker on empty trace
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2021-12-05 shortcut for creating linked markers for all traces
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2022-01-05 attempt to connect at startup with empty devicelist (triggers udev info msg)
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2022-01-13 Bugfix: time gate filter size, improve dialog shutdown
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2022-01-29 Fix: prevent crash when closing preferences without connected device
2022-02-22 Move statusbar update slot to correct thread
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2022-03-03 attempt to fix --no-gui option for windows
    [main.cpp]
2022-03-07 Update to STM32CubeIDE + longer settling time for point 0
    [New_configuration.cfg, VNA_embedded Debug.cfg]
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2022-06-18 traceplot: update trace color in plots
    Fixes #114
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2022-06-23 Fix generator output spikes
    - Add manual overwrite in FPGA for hardware that is usually handled by sweep control
    - Use static hardware configuration for generator (no sweep active anymore)
    [FPGA.cpp, Hardware.cpp, Hardware.hpp]
2022-06-25 Fix STM temperature calculation
    [VNA_embedded.ioc, main.c]
2022-06-26 Fix further sweep timeout issues
    [FPGA.cpp, Hardware.cpp, VNA_embedded.ioc]
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2022-07-04 app: fix init and disconnect device in active mode
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2022-07-11 Math traces bugfixes + comments
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2022-07-16 app: refactor enable connect to
    Instead of enabling multiple times "connect to" by iterating
    over device list, let's use a flag that determine when at
    least one device was found. In that way, the enabling method
    is executed once.
2022-07-17 Minor pull-request adjustments
    - Restore active mode after amplitude calibration
    - Keep order of modes as before (must users are probably used to that order by now)
    - Use correct parent for name popup when creating new modes
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2022-08-23 Fix trace parsing of old setup files
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2022-10-01 Version number increase + boot LED debug reverted
    [VNA_embedded.ioc, main.c, main.h]
2022-10-08 Prevent X axis label clipping for large font sizes
2022-10-13 Github actions test for calibration crash
2022-10-14 Prevent activating calibration without defined calibration standard
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2022-10-23 eye diagram thread rework + uninitialized variables fix
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2022-10-25 Improve autoscaling when no traces are visible, fix display issue of long tick labels
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2022-10-31 Fix calibration bug + improve device shutdown
2022-11-02 Fix calibration measurement interpolation bug
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2022-11-13 Save/load calkit SCPI command + re-entrancy bugfix during calibration
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2022-11-17 Merged hardware changes from layout_6_layers
    [BottomShield.step, LOcutNoCase.csv, OutputPower.csv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]
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2022-11-17 Bugfix calibration range calculation
2022-11-19 Hardfault handler + FPGA abort/interrupt collision fix
    [FPGA.cpp, Hardware.cpp]
2022-11-19 Manufacturing files
    [Legend_Bot.gbr, Legend_Top.gbr, Paste_Bot.gbr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]
2022-11-27 correction to usb device PID reference
2022-11-29 replace USB protocol literals with named constants
    [PacketConstants.h]
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2022-12-07 Fix reference impedance for de-embedding traces
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2022-12-11 keep original trace data when de-embedding, toggle de-embedding view for individual traces
2022-12-12 fix wrong format when saving 2xthru de-embedding
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2022-12-13 Prevent error message when connecting to compound device on Windows
2022-12-13 Prevent updating trace widget for every added de-embedding point
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2022-12-16 Fix device connection when loading setups
2022-12-20 Revert "evaluate AUX3 in standby state"
    This reverts commit ec5e0e208cde31100c5c5b976332cd1d0499e69a.
    [FPGA.cpp, Hardware.cpp]
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2023-01-14 Fix min calibration frequency after taking measurement
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2023-02-15 Fix trace point calculation on distance X axis
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2023-02-17 When failing to open a device show normal message instead of error
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2023-03-01 Fix impedance for mixed mode traces
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2023-03-21 Fix polarity of fixed power setting in protocol documentation
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2023-03-24 LibreVNA-GUI: Fix usage of QAbstractSocket's slot 'errorOccurred'
2023-03-24 LibreVNA-GUI:Traces:tracepolot: Fix getting QWheelEvent position
2023-04-03 Ignore first point of next sweep when in single sweep mode, fix parsing of VFF MCU temperature in VNA log
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2023-07-30 Fix calibration progress dialog
2023-09-05 Fix missing device log if USB connection is not established at power up
    [usb.c]
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2023-12-15 Fix for de-embedding menu on macOS
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2024-01-04 Bugfixes LibreCAL automatic calibration dialog
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2024-02-08 prevent crash when device disconnects while a dialog acquired control
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2024-02-26 update BOM and PDF schematic
    [BOM.ods]
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2024-02-27 Fix size of device configuration dialog
2024-02-29 Moved EAGLE files into own directory
    [BOM.ods, VNA.brd, VNA.sch]
2024-02-29 Added Initial Kicad Board
    [AttenuatorSwitches.kicad_sch, FPGAConnections.kicad_sch, FPGAMicrocontroller.kicad_sch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]
2024-03-01 Generated Gerbers
    [VNA-B_Cu.gbl, VNA-B_Mask.gbs, VNA-B_Paste.gbp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]
2024-03-01 Moved Old Gerbers into Eagle Subdirectory
    [Legend_Bot.gbr, Legend_Top.gbr, Paste_Bot.gbr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]
2024-03-01 Fix impedance renormalization and honor new reference impedance for traces
2024-03-01 update smith chart reference impedance when trace impedance changes but keep smith lines in place
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2024-03-12 Swapped LED1 and LED2
    1) Swapped LED1 and LED2 identifiers to be consistent with original schematic and correct color in BOM
    [FPGAConnections.kicad_sch, FPGAMicrocontroller.kicad_sch]
2024-03-13 Removed Unused vias per DRC [Net-(IC34-EN)], [PORTSW2_CTL_F], [PORTSW1_CTL_F], [Net-(IC30-EN)] Reverted Soldermask Extension for top cover plate Regenerated Gerbers
    [PowerSupply.kicad_sch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]
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2024-03-26 Production files
    Production files as sent to fabricator.
    Includes various PCB cleanup an the TCXO footprint change due to an unavailable part.
    [LocalOsc2_RefClock.kicad_sch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]
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2024-04-22 Stop sweep after reset, fix failing tests
    [Hardware.cpp]
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2024-05-10 Check for ID collisions when loading calibration standards
2024-05-17 Improve taking de-embedding measurements
    - Automatically restart measurement even when the sweep was stopped
    - Fix crash due to zeroed de-embedding reference impedance
    - Fix crash due to not cleaned up dialog pointer with dangling connections
    - Automatically excite the correct ports for the measurement
2024-06-24 Fix SCPI parsing for arguments containing ':'; allow lower case calibration file names
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2024-09-18 allow calibration to continue with missing measurements (better than doing nothing)
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2024-12-03 fix: clean device disconnection when loading setup files
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2024-12-17 add mutex for trace data (fixes DFT/TDR thread crashes)
    [main.cpp]
2025-01-02 WIP: rework 2.LO + add dwell time
    [FPGA.cpp, Hardware.cpp, Hardware.hpp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]
2025-01-03 Working dwell time feature
    - Bugfixes:
    - improve SPI timing in FPGA
    - fix markers and reduce CPU load when using markers with fast traces
    - New features:
    - dwell time configurable in acquisition toolbar
    - PLL settling delay in device configuration
    - device configuration persistent across power cycles
    [FPGA.cpp, Hardware.cpp, Hardware.hpp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]
2025-01-05 fix order of LO1 and source unlock LEDs
2025-01-06 Startup and communication bugfixes
    - reduce amount of mode switched when starting and loading setups
    - improve logging for errors during HIL tests
    - fix small USB communication bugs
    [usb.c]
2025-01-07 Short switch to idle when the reference is changed
2025-01-08 use trace model source and correct units for graph axes and edit dialogs
2025-02-09 Fix impedance renormalization + add unit tests
    [main.cpp]
2025-02-14 Various bugfixes, mostly eye diagram related
    - Update eye diagram when settings are changed but data is static
    - Keep trace on eye diagram visible when random other trace is deleted
    - resolve references when duplicating a math trace
    - use correct trace output domain in various checks throughout the code
2025-02-21 Improve de-embedding
    - Add Z parameters with general conversion from and to S parameters
    - Implement impedance renormalization over general Z parameters
    - Fix crash after taking de-embedding measurement
    - Fix various small bugs with new parameter implementation
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2025-02-27 Mar 2024 KiCad PWB as-built w/ fixes
    Includes all updates made to Mar 2024 version of KiCad PWB plus fixes found during assembly. Update board version to Feb 2025.
    [LibreVNA Kicad PCB.csv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]
2025-02-27 prevent race condition when aborting calibration measurement
2025-02-28 disable start button when determining ports, reset stylesheet instead of forcing black
2025-03-03 Reset LibreCAL port standards to none when aborting calibration measurement.
2025-03-03 switch PLL reference to avoid integer spurs
2025-03-05 fix de-embedding menu on macOS after loading setup (#297)
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2025-04-23 fix missing initialization for compound device in SA mode
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2025-05-06 fix buffer overflow when combining de-embedding with custom expressions
2025-05-12 Fix: do not reset variable names for from math traces when opening trace edit dialog
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2025-06-23 Custom expression bugfixes
    - Off-by-one error when number of input samples changes
    - race condition when closing custom expression edit dialog
    - adjust available variables when input data type changes
2025-06-24 option to prevent electronic calibrations while LibreCAL temperature unstable
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2025-07-27 change LM3370 MPN to LM3370SD-3021(defualt 1.2v for buck 1)
    [PowerSupply.kicad_sch]
2025-08-09 Bugfix: correct PLL configuration at the band switch frequency (25 MHz)
2025-08-10 Calibration error term model view
    [calibrationviewdialog.h]
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2026-03-06 set layout stretch to fix button size on automatic builds
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2026-04-07 Bugfix: always update math traces if number of points is reduced
    - mathUpdateEnd may still be set to a high value when the size update of
    data and the call to schedule the math update overlap
    - force mathUpdateEnd to be at or below data.size whenever the points of
    the math traces are updated
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2026-06-12 update Windows Qt to 6.8.3, fixes menus opening on the wrong screen
    Qt 6.2.4 contains a screen-detection regression (QTBUG-101203, fixed
    in Qt 6.2.5): monitors reporting identical device names (two external
    monitors of the same model) are treated as a single physical screen.
    QMenu popups on the affected monitor then position against the wrong
    screen geometry, appearing detached from the menu bar or on another
    display entirely. The bug only reproduces with identical-model
    monitor pairs, which is why reports of it have been inconsistent.
    Qt 6.8.3 (LTS) also includes later popup placement fixes
    (QTBUG-118695, QTBUG-120011) and reworked Windows DPI handling.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
2026-06-17 Fix trace data race in TDR calculation
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2026-11-08 zero-span calibration fix
2026-11-08 minor fix: return and set CS high if SPI transfer fails to start
2026-11-08 catch I2C read errors, fix potential CLK6/7 error
2026-11-08 fix handling of errors in VCO map and temperature reading
2026-11-08 Various bugfixes around calibration, flash and hardware control, mostly just hardening against bad data
    - typo fix when checking PLL status from Si5351
    - helper function for writing arbitrarily long flash data (prevents reading past buffer and writing random RAM content to unused areas of flash)
    - Amplitude calibration receive handling catches bad number of total points
    - improved error handling when flash erasing fails
2026-11-08 fix calculation of total points when loading partial calibration coefficients

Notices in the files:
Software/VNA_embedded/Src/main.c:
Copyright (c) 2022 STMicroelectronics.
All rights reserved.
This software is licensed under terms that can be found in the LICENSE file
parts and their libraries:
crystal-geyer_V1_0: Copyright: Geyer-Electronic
